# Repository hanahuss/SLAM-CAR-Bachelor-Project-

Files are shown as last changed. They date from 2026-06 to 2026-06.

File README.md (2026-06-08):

# SLAMborghini

> We built a SLAM car that explores rooms on its own, no laptop, no GPS, no internet. It sees the world through a spinning LiDAR, builds a live map as it drives, and figures out where to go next all by itself. Everything runs on two tiny ESP chips talking to each other in real time.

<p align="center">
  SLAMborghini RC Car
</p>

**Course:** [Making Intelligent Things (CS-358)](https://edu.epfl.ch/coursebook/en/making-intelligent-things-a-CS-358-A) EPFL Spring 2026

**Team:** Sara Amoussi · Chahd Achkrou · Hala Dina Ben Khaddah · Yassine Elhachimi · Hana Hesham Anwar Hussein

---

## Project Context

**Overview**

SLAMborghini implements **Simultaneous Localization and Mapping (SLAM)** on a resource-constrained RC car platform. The system solves the classic SLAM issue, building a map while simultaneously tracking position within it, built around three core components:

1. **Mapping**: The map is a sparse quadtree, it recursively divides the arena into smaller and smaller cells, only allocating memory for regions the robot has actually observed. This makes it extremely memory-efficient on the microcontroller. The car continuously builds its map using data from the RPLiDAR. Each ray traces through space, marking cells it passes through as free and stamping the wall it hits as occupied. Evidence builds up over time, the more a wall gets confirmed, the more confident the map becomes. When memory starts running low, the system automatically clears out uncertain areas while keeping the walls it's already sure about, so the map stays reliable without running out of space.
2. **Localization**: The car always knows where it is, even when things get tricky. Between each LiDAR scan, odometry keeps track of its position, the wheel encoder measures how far it's moved and the IMU sensor tracks which way it's turned. But small errors add up over time, so every time a new scan comes in, a two-level correlative scan matcher compares what the LiDAR sees with what's already on the map and corrects any drift. If the scan matcher doesn't find a confident match, the system falls back to pure odometry rather than applying a bad correction, keeping the map stable even in featureless environments.
3. **Navigation**: The car decides where to go by looking at frontiers, the boundaries between areas it has already mapped and areas still unknown. A Wavefront Frontier Detection algorithm scans outward through free cells, clusters these boundaries together, and picks the closest significant one as the next target. Hybrid A* then plans a path to that target, respecting the car's Ackermann steering constraints so the path is actually drivable. The path is streamed in chunks over UART from the ESP32-S3 to the Wemos, where a Pure Pursuit controller executes it in real time by continuously steering toward a lookahead point on the path.

<p align="center">
  <b>🗺️ Live SLAM Mapping Demo</b>
</p>
<p align="center">
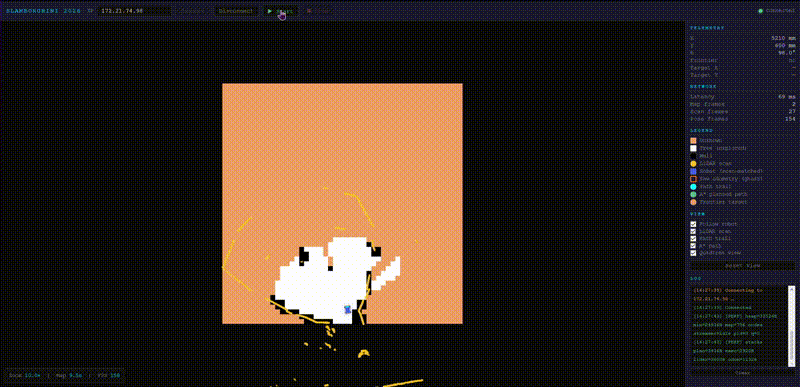
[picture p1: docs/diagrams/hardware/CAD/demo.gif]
SLAMborghini Demo
  
</p>

The key design decision is a **two-chip architecture**: the ESP32-S3 is the brain, it sees through the LiDAR, builds the map, figures out where to go, and sends path commands down to the Wemos over UART. The Wemos is the body, it owns the motors, the servo, and the sensors that measure motion, and it executes whatever the S3 tells it to drive. This clean split keeps the high-level thinking and the physical actuation fully independent, eliminating the timing conflicts that caused map drift when both were crammed onto one core.

Every bit of sensing, mapping, planning, and motor control happens on those two chips: no laptop, no cloud, no ROS. Just two microcontrollers talking to each other and figuring it out.

---

## Quick Jump To Detailed Documentation

For in-depth technical details, refer to the dedicated subsystem documentation:

<table>
<tr>
<td width="50%" align="center">

### 🧠 **[ESP32-S3: SLAM Brain](esp32s3/)**

LiDAR driver, quadtree map, correlative scan matching, RBPF, frontier detection, Hybrid A\*, Wi-Fi dashboard

</td>
<td width="50%" align="center">

### 🚗 **[Wemos D1 R32: Control Brain](wemos/)**

AS5600 encoder, ICM-20948 IMU, Ackermann odometry, Pure Pursuit controller, motor/servo control

</td>
</tr>
</table>

---

## Table of Contents

1. [Project Overview](#project-overview)
2. [Quick Start](#quick-start)
3. [Hardware](#hardware)
4. [System Architecture](#system-architecture)
5. [Software Setup](#software-setup)
6. [Configuration & Tuning](#configuration--tuning)
7. [Tools & Dashboard](#tools--dashboard)
8. [Known Issues & Limitations](#known-issues--limitations)
9. [Credits](#credits)

---

## Project Overview

### Vision

SLAMborghini is a fully autonomous RC car that you place in any unknown indoor space. It explores, builds a precise 2D floor plan in real time, and then navigates that space continuously, with no GPS signal, no connected laptop, and no cloud backend.

The full vision is laid out in the [Project Proposal](SLAMborghini-Proposal-1.pdf),  what's running today is Phase 1: full SLAM and autonomous patrol.

### How the Robot "Thinks"

The system runs a closed-loop pipeline, sense, plan, act, continuously and in real time, with responsibilities divided across two processors:

**High-Level Decision Making (ESP32-S3 SLAM Brain):**
1. **Perceive**: Read one 360° LiDAR scan (~100 ms per rotation)
2. **Correct**: Run correlative scan matching against the existing map to remove odometry drift
3. **Map**: Integrate the corrected scan into the sparse quadtree occupancy map
4. **Plan**: Detect exploration frontiers (free/unknown boundaries) → select nearest large frontier → run Hybrid A\* to compute a kinematically feasible path
5. **Command**:  Send the planned path to the Wemos over UART in small chunks of waypoints at a time, rather than all at once, so the Wemos always has the next steps ready without needing to buffer the entire route

**Low-Level Execution (Wemos D1 R32 Control Brain):**
1. **Localize**: Fuse AS5600 encoder distance with ICM-20948 gyro IMU heading at 100 Hz
2. **Track**: Follow the incoming path using Pure Pursuit; report consumed waypoints back
3. **Report**: Send odometry packets to the S3 at 20 Hz for pose integration

**Why this split?** SLAM and motor control have fundamentally different timing requirements. The S3 needs long uninterrupted windows to process LiDAR scans and update the map. The Wemos needs to fire motor commands at a tight, consistent rate to keep the car stable. When both tasks competed for the same processor, the motor interrupts would disturb the scan timing just enough to corrupt the map. Separating them onto dedicated chips eliminated that interference entirely.

### Technical Vocabulary

- **ESP32-S3**: Xtensa LX7 dual-core @ 240 MHz, 8 MB PSRAM, built-in Wi-Fi (SLAM Brain)
- **Wemos D1 R32**: ESP32 LX6 dual-core @ 240 MHz (Control Brain)
- **RPLiDAR C1**: 360° laser rangefinder, 12 m range, 10 Hz 
- **AS5600**: 12-bit I2C magnetic rotary encoder for wheel odometry
- **ICM-20948**: 9-DOF IMU; gyro Z only used (magnetometer disabled near motors)
- **IBT-4**: 50A MOSFET H-bridge motor driver
- **Quadtree**: Hierarchical spatial index; 4000 nodes × 12 B = 48 KB for a 10 m × 10 m map
- **Correlative scan matching**: Exhaustive 2-level grid search over (dx, dy, dθ), deterministic, ~5 ms
- **Hybrid A\***: Kinematically-constrained A\* that respects Ackermann steering limits
- **Pure Pursuit**: Geometric path-tracking controller for car-like robots
- **RBPF**: Rao-Blackwellized Particle Filter (module exists; currently pose integration uses direct complementary fusion)
- **UART bridge**: 115 200 baud serial link between S3 and Wemos; custom framed binary protocol

### Key Objectives 

- Real-time SLAM on a microcontroller with a full cycle time under 10 ms
- Sparse quadtree occupancy map of any unknown indoor room within 2 minutes of autonomous exploration
- Continuous autonomous frontier-based exploration and patrol along a Hybrid A\* route
- Stable differential odometry using the AS5600 magnetic encoder + ICM-20948 gyro fusion
- Live occupancy map streamed to a Wi-Fi dashboard accessible from any browser

---

## Quick Start

### Prerequisites Checklist

**Hardware:**
- Assembled SLAMborghini car (see [Hardware section](#hardware))
- 7.4 V LiPo battery (charged)
- USB-C to USB-C cable for flashing the ESP32-S3
- USB-C to Micro-USB cable for flashing the Wemos D1 R32
- Computer on the same Wi-Fi network as the car

**Software:**
- [PlatformIO Core](https://docs.platformio.org/en/latest/core/index.html) or VS Code extension

### Flash & Run

**Step 1: Clone the Repository**
```bash
git clone https://github.com/epfl-cs358/2026sp-SLAMborghini.git
cd 2026sp-SLAMborghini
```

**Step 2: Set Wi-Fi Credentials**

Edit [esp32s3/main.c](esp32s3/main.c) lines 74–75 before flashing:
```c
#define WIFI_SSID      
#define WIFI_PASSWORD  
```

**Step 3: Flash the ESP32-S3 (SLAM Brain)**
```bash
# In VS Code with PlatformIO:
# 1. Connect ESP32-S3 via USB
# 2. Open PlatformIO extension (alien icon)
# 3. Go on the terminal, type: cd esp32s3, and then type: pio run -e esp32s3 -t upload 
```

**Step 4: Flash the Wemos D1 R32 (Control Brain)**
```bash
# 1. Connect Wemos via USB
# 2. Click wemos → General → Upload, cd wemos, and then type: pio run -e wemos_slam -t upload 
```

**Step 5: Power Up**
1. Connect the 7.4 V LiPo battery
2. Open a browser and navigate to the IP address printed on the ESP32-S3 serial monitor
3. Open `tools/dashboard/live_dashboard.html`, enter the ESP32-S3 IP address
4. Click **Start** to begin autonomous exploration

**What to expect:**
- Live dashboard shows the occupancy map building in real time
- Robot explores frontiers and navigates toward them autonomously

---

## Hardware

### Component List

| # | Component | Model / Spec | Qty | Status |
|---|---|---|-----|---|
| 1 | ESP32-S3 dev board | ESP32-S3-WROOM-1, 8 MB PSRAM | 1 | Order |
| 2 | Magnetic encoder + magnet | AS5600 + 6 mm magnet | 1 | Order |
| 3 | RPLiDAR C1 | Slamtec, 12 m, 10 Hz | 1 | Existing |
| 4 | ICM-20948 IMU | 9-DOF, magnetometer disabled | 1 | Existing |
| 5 | Wemos D1 R32 | ESP32 LX6, 4 MB flash | 1 | Existing |
| 6 | ESP32-CAM AIThinker | OV2640 2 MP | 1 | Existing (stub only) |
| 7 | IBT-4 motor driver | 50A MOSFET H-bridge | 1 | Existing |
| 8 | DMS15-270 servo | 15 kg·cm, 270° range | 1 | Existing |
| 9 | LM2596 buck converter | 7.4 V → 5 V, 3 A | 1 | Existing |
| 10 | LiPo battery 7.4 V 3000 mAh 2S | RedPower + HW-391 BMS | 1 | Existing |
| 11 | Active buzzer 5 V | 85 dB piezo | 1 | Stock |
| 12 | Electrolytic cap 1000 µF 16V | Motor/logic rail decoupling | 2 | Stock |
| 13 | 1N4007 diode | Flyback protection | 4 | Stock |
| 14 | 4.7 kΩ resistor | I2C pull-ups (6 total) | 6 | Stock |

### 3D Printed Parts

All custom mechanical parts were designed in CAD and printed in PLA. Source files (`.step` for editing, `.stl` for slicing) are in [`docs/diagrams/hardware/CAD/`](docs/diagrams/hardware/CAD/).

<table>
<tr>
<td width="50%" align="center">

**Encoder Bracket**

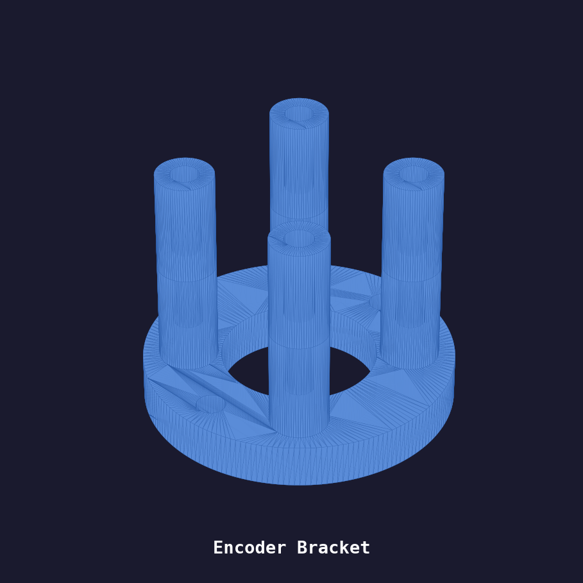
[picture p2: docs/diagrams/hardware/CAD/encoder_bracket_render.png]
Encoder Bracket


Mounts the AS5600 encoder at the rear wheel<br>
[📄 STL](docs/diagrams/hardware/CAD/Encoder_Bracket.stl) · [📐 STEP](docs/diagrams/hardware/CAD/Encoder_Bracket_v1.step)

</td>
<td width="50%" align="center">

**Magnet Support**

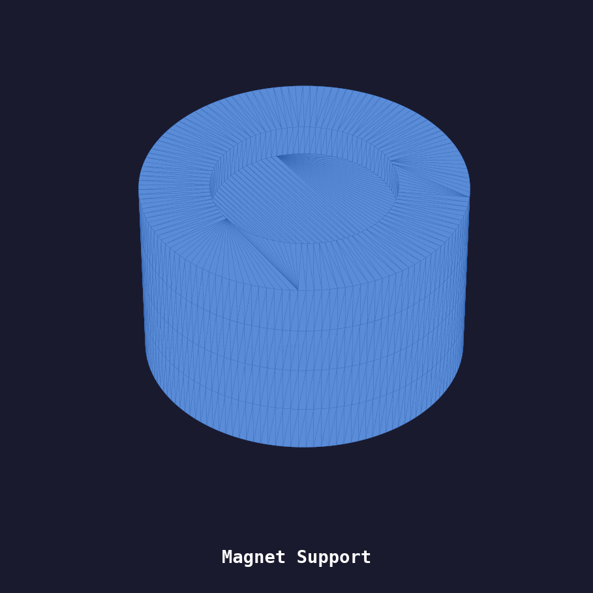
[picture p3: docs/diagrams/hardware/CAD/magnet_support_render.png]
Magnet Support


Holds the 6 mm magnet centred on the wheel axle<br>
[📄 STL](docs/diagrams/hardware/CAD/Magnet_Support.stl)

</td>
</tr>
<tr>
<td width="50%" align="center">

**Protection Cover**

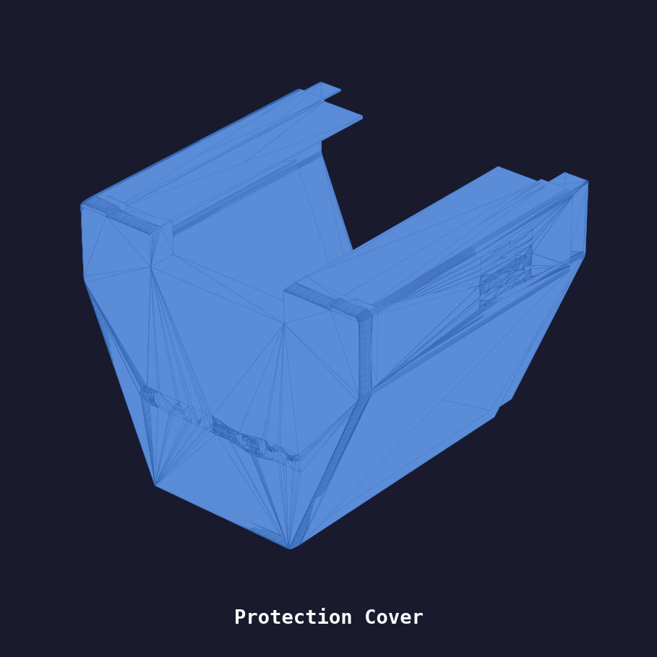
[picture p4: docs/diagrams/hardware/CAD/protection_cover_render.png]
Protection Cover


Shield over the electronics bay<br>
[📄 STL](docs/diagrams/hardware/CAD/Protection_Cover.stl) · [📐 STEP](docs/diagrams/hardware/CAD/Protection_Cover.step)

</td>
<td width="50%" align="center">

**Electronics Tray**

Electronics Tray

Chassis-mounted tray for all PCBs and modules<br>
[📄 STL](docs/diagrams/hardware/CAD/electronics_tray.stl) · [📐 STEP](docs/diagrams/hardware/CAD/electronics_tray.step)

</td>
</tr>
</table>

> **Recommended print settings:** PLA, 0.2 mm layer height, 20% infill, 3 perimeters. The Encoder Bracket and Magnet Support are precision-fit parts, print at 100% scale with no scaling.

### Pin Assignment Summary

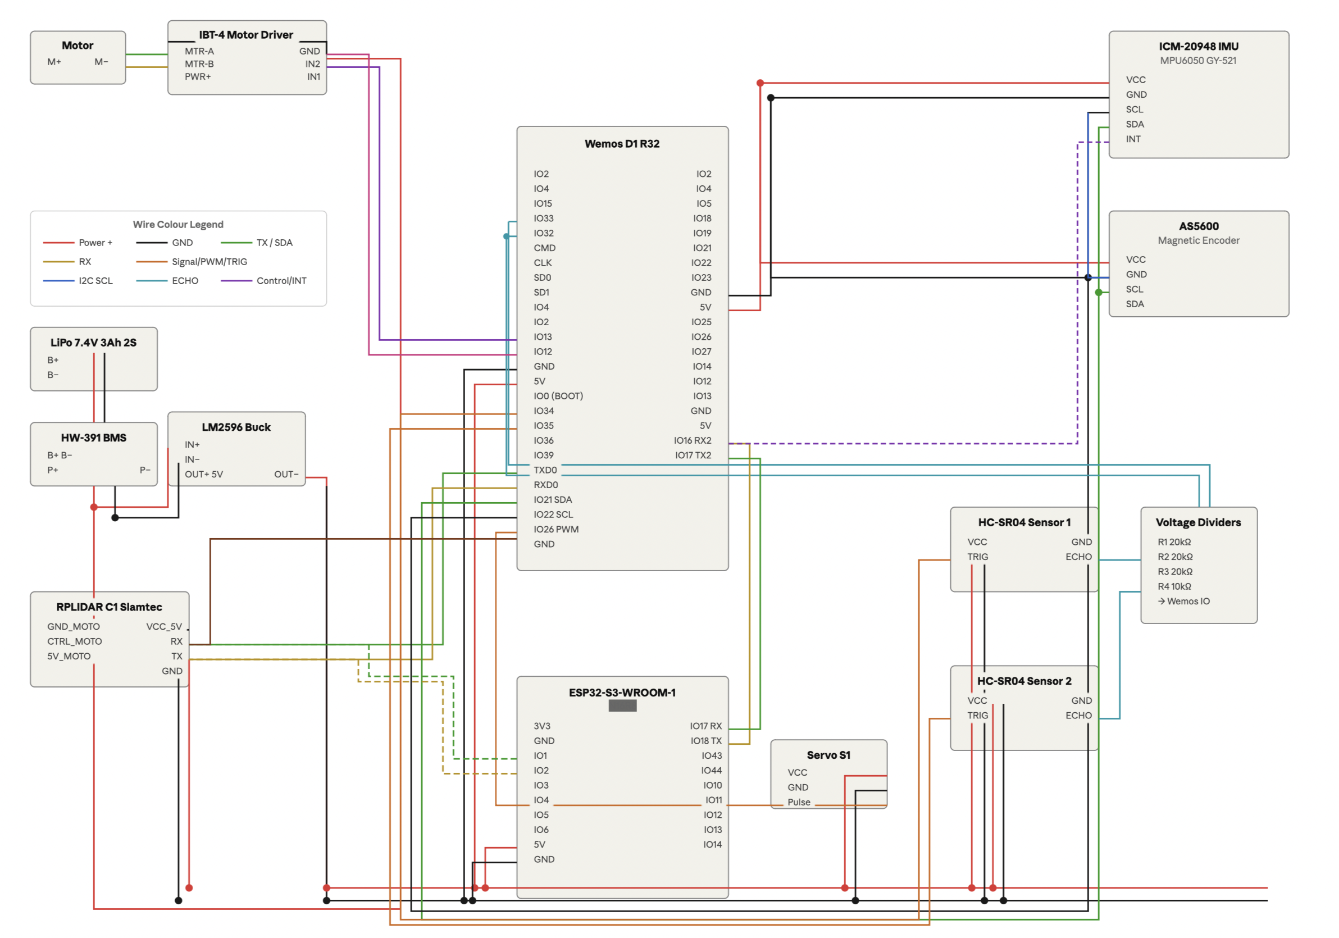
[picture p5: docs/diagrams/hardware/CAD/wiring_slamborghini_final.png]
Wiring Diagram


**ESP32-S3:**

| GPIO | Function | Connected to |
|---|---|---|
| GPIO14 (RX) | UART1 LiDAR | RPLiDAR C1 TX |
| GPIO13 (TX) | UART1 LiDAR | RPLiDAR C1 RX |
| GPIO17 (TX) | UART2 Bridge → Wemos | Wemos GPIO16 |
| GPIO16 (RX) | UART2 Bridge ← Wemos | Wemos GPIO17 |

**Wemos D1 R32:**

| GPIO | Function | Connected to |
|---|---|---|
| GPIO21 | I2C SDA | AS5600 + ICM-20948 |
| GPIO22 | I2C SCL | AS5600 + ICM-20948 |
| GPIO16 (RX) | UART2 Bridge | ESP32-S3 GPIO17 |
| GPIO17 (TX) | UART2 Bridge | ESP32-S3 GPIO16 |
| GPIO19 | IBT-4 RPWM (forward) | IBT-4 IN1 |
| GPIO13 | IBT-4 LPWM (backward) | IBT-4 IN2 |
| GPIO2 | Servo PWM | DMS15-270 |
| GPIO14/27 | HC-SR04 A TRIG/ECHO | Front-left sonar |
| GPIO25/26 | HC-SR04 B TRIG/ECHO | Front-right sonar |

### Power Architecture

The system runs from a single 7.4 V LiPo with a dual-rail split:

| Rail | Voltage | Source | Powers |
|---|---|---|---|
| Motor rail | 7.4 V direct | LiPo → HW-391 BMS → IBT-4 | IBT-4 only |
| Logic rail | 5 V regulated | LiPo → HW-391 BMS → LM2596 | All ESP32 boards, RPLiDAR, HC-SR04, servo |
| 3.3 V sub-rail | 3.3 V | Onboard ESP32 regulators | ICM-20948, AS5600 |

Motor GND and logic GND are separated physically; one controlled common reference point near power entry.

---

## System Architecture

Computation is split across two ESP32s with clearly defined roles:

- **ESP32-S3**: SLAM pipeline, frontier exploration, global planning, Wi-Fi dashboard
- **Wemos D1 R32**: Sensor fusion, Pure Pursuit execution, motor/servo control

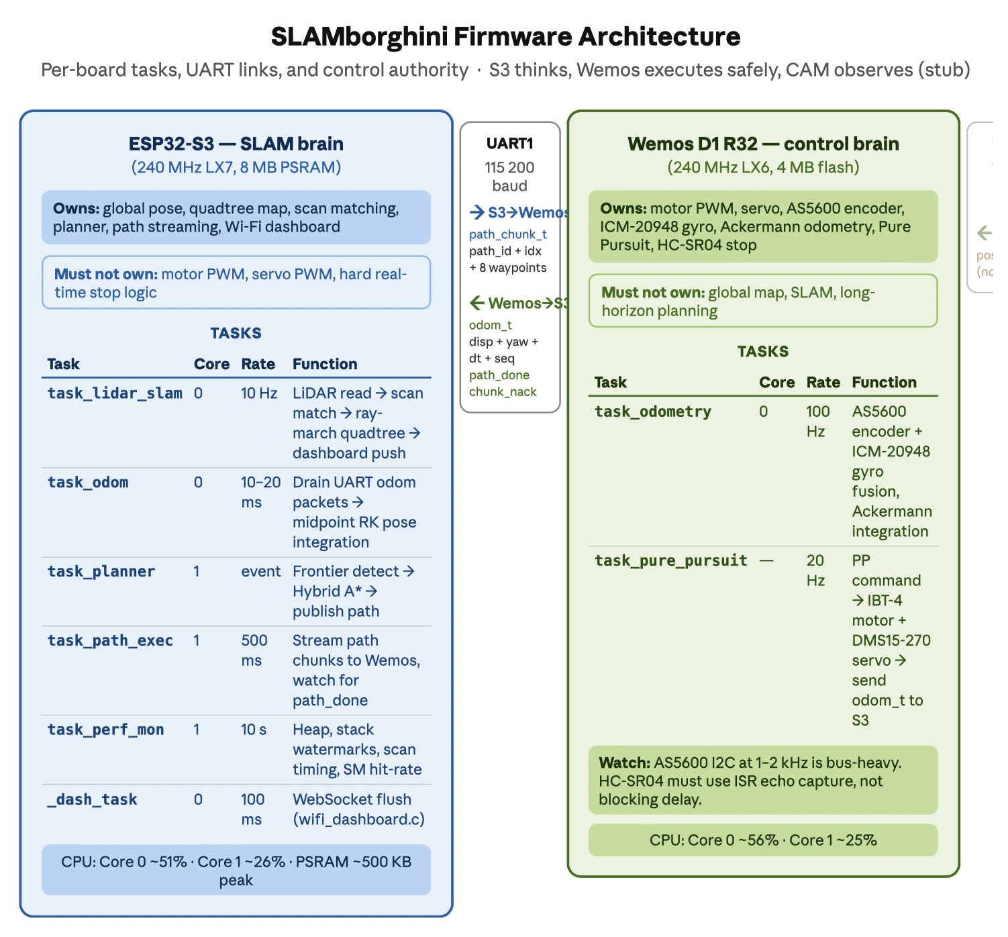
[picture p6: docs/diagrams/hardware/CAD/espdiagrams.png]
Firmware Architecture


Both run **FreeRTOS** for priority-based real-time scheduling. The S3 connects to the existing Wi-Fi network and serves a live HTTP + WebSocket dashboard.

```
────────────────────────────────────────────────────────────────────────
  ESP32-S3  SLAM Brain  (10 Hz SLAM loop)
  • LiDAR driver + correlative scan matching
  • Sparse quadtree occupancy map (48 KB, 4000 nodes, 10 m × 10 m)
  • RBPF 20-particle pose estimator
  • Wavefront Frontier Detection + Hybrid A* planner
  • Frontier blacklisting, path streaming to Wemos
  • Wi-Fi HTTP + WebSocket dashboard (live map, pose, path overlay)
────────────────────────────────────────────────────────────────────────
                     UART  115 200 baud
  odom_t packets ←   (linear_disp_mm, yaw_rate_imu, dt_ms, seq)
  path_chunk_t  →    (path_id, start_index, 8 waypoints per chunk)
  path_done     ←    (signal: path complete, please replan)
  chunk_nack    ←    (signal: out-of-order chunk, resend from index N)
────────────────────────────────────────────────────────────────────────
  Wemos D1 R32  Control Brain  (20–100 Hz control loops)
  • AS5600 encoder + ICM-20948 gyro fusion at 100 Hz
  • Ackermann odometry model
  • Pure Pursuit path tracking (20 Hz, 32-waypoint ring buffer)
  • IBT-4 motor PWM + DMS15-270 servo control

────────────────────────────────────────────────────────────────────────
```

### ESP32-S3 Tasks

| Task | Core | Priority | Period | Function |
|---|---|---|---|---|
| `task_lidar_slam` | 0 | 7 | ~100 ms | LiDAR read → scan match → ray-march → dashboard push |
| `task_odom` | 0 | 6 | 10 ms | Drain UART odom packets → midpoint RK pose integration |
| `task_planner` | 1 | 3 | event-driven | Frontier detect → Hybrid A\* → publish path to exec |
| `task_path_exec` | 1 | 3 | 500 ms | Stream path chunks to Wemos, watch for path_done |
| `task_perf_mon` | 1 | 1 | 10 s | Heap, stack watermarks, scan timing, SM hit-rate |
| `_dash_task` | 0 | 1 | 100 ms | WebSocket flush (inside wifi_dashboard.c) |

### Wemos D1 R32 Tasks

| Task | Core | Priority | Period | Function |
|---|---|---|---|---|
| `task_odometry` | — | 5 | 10 ms (100 Hz) | AS5600 read + IMU fusion + Ackermann integration |
| `task_pure_pursuit` | — | 4 | 50 ms (20 Hz) | PP command → motor/servo → send odom_t to S3 |

### SLAM Pipeline (one cycle)

```
LiDAR scan (~100 ms blocking read)
    │
    ▼
Snapshot raw odometry pose
    │
    ▼
Correlative scan matching (~5 ms)
  • Coarse: ±100 mm / 50 mm,  ±8° / 4°  → 125 candidates
  • Fine:   ±20 mm / 10 mm,   ±2° / 1°  → 125 candidates
  • Rejection: hit-rate < 10%  OR  |Δ| > 80 mm / 12°
    │
    ▼
Apply correction to running pose estimate
    │
    ▼
Ray-march scan into quadtree map (Bresenham per beam)
  • HIT +30, MISS −2  (15:1 ratio — walls resist free-space erosion)
  • Auto-compact at 85% pool usage: snapshot walls ≥ 10, wipe, re-insert
    │
    ▼
Frontier detection + A* (on planner task, 500 ms replan budget)
    │
    ▼
Stream path chunks to Wemos (8 waypoints/chunk, NACK-retry protocol)
```

### Communication Protocol (UART Bridge)

| Direction | Message | Size | Rate |
|---|---|---|---|
| Wemos → S3 | `odom_t` (linear_disp + yaw_rate + dt + seq + consumed_wp) | 20 B | 20 Hz |
| S3 → Wemos | `path_chunk_t` (path_id + start_index + 8 waypoints) | 136 B | on replan |
| Wemos → S3 | `path_done` marker | 4 B | on path complete |
| Wemos → S3 | `chunk_nack` (path_id + expected_index) | 4 B | on out-of-order |

The path streamer on the S3 maintains a sliding window of the planned path and proactively tops up the Wemos ring buffer as consumed waypoints are reported.

---

## Software Setup

### Project Structure

```
2026sp-SLAMborghini/
├── esp32s3/                   # SLAM Brain firmware
│   ├── main.c                 # Tasks: lidar_slam, odom, planner, path_exec, perf_mon
│   └── src/
│       ├── lidar_driver.c/h   # RPLiDAR C1 UART driver
│       ├── lidar_to_map.c/h   # Bresenham ray-march into quadtree
│       ├── quadtree_map.c/h   # Sparse quadtree occupancy map
│       ├── scan_matcher.c/h   # Two-level correlative scan matching
│       ├── rbpf.c/h           # Rao-Blackwellized Particle Filter
│       ├── frontier_detector.c/h  # Wavefront Frontier Detection (WFD)
│       ├── hybrid_astar.c/h   # Hybrid A* path planner
│       ├── path_streamer.c/h  # Chunked path streaming + NACK retry
│       ├── uart_bridge.c/h    # Framed binary UART protocol
│       └── wifi_dashboard.c/h # HTTP + WebSocket live dashboard
│
├── wemos/                     # Control Brain firmware
│   ├── main.c                 # Tasks: task_odometry, task_pure_pursuit
│   ├── imu_gyro.c/h           # ICM-20948 gyro-Z driver
│   └── src/
│       ├── task_odometry.c/h  # 100 Hz sensor fusion task
│       ├── imu_encoder_driver.c/h  # AS5600 encoder + IMU read
│       ├── encoder_ackermann_odometry.c/h  # Ackermann kinematic model
│       ├── pure_pursuit_controller.c/h  # Pure Pursuit + ring buffer
│       └── uart_bridge.c/h    # Framed binary UART protocol (Wemos side)
│
├── esp32cam/                  # Vision Brain (stub — not functional)
│   └── main.c                 # posture_classifier_init() only; loop commented out
│
├── tools/
│   ├── dashboard/
│   │   ├── live_dashboard.html       # Main browser UI (WebSocket map + pose)
│   │   ├── frontier_dashboard.html   # Frontier overlay debug view
│   │   └── playback_dashboard.html   # Replay from room.log
│   ├── parse_room/
│   │   └── parse_room.py             # Convert room.log to map image
│   └── slam_sim.py                   # SLAM simulator (desktop testing)
│
├── hardware_pins.h            # All GPIO assignments (edit here to rewire)
├── types.h                    # Shared data structures (both boards)
└── profiler/                  # FreeRTOS CPU profiling helper
```

### Development Environment

**Prerequisites:**
- [PlatformIO Core](https://docs.platformio.org/en/latest/core/index.html) or VS Code extension
- ESP-IDF v5.x (bundled by PlatformIO, no separate install needed)

### Flash ESP32-S3

```bash
cd esp32s3
# Via PlatformIO CLI:
pio run -e esp32s3 -t upload
pio device monitor
```

### Flash Wemos D1 R32

```bash
cd wemos
pio run -e wemos_slam -t upload 
pio device monitor
```

### Wi-Fi Configuration

Edit [esp32s3/main.c](esp32s3/main.c) before flashing:
```c
#define WIFI_SSID      "your_network"
#define WIFI_PASSWORD  "your_password"
```

The ESP32-S3 connects to your existing Wi-Fi (station mode, not AP). The IP address is printed on the serial monitor at boot.

---

## Configuration & Tuning

### Map Parameters

```c
// esp32s3/main.c — app_main()
quadtree_map_init(&s_map, 10000.0f, 10000.0f, 156.0f);
//                         ^width mm  ^height mm  ^leaf cell mm
```

10 m × 10 m arena with 156 mm leaf resolution (10 000 / 64, depth 7).

```c
// esp32s3/src/quadtree_map.h
#define QT_POOL_SIZE  4000   // 4000 × 12 B = 48 KB
#define QT_MAX_DEPTH  7
#define QT_HIT_INC    30     // log-odds increment on obstacle hit
#define QT_MISS_DEC  (-2)    // log-odds decrement per free-ray pass
```

**Trade-offs:**
- Larger `QT_POOL_SIZE` → more map detail → more RAM (must fit in D-cache for scan matching)
- Higher `QT_HIT_INC` / lower `QT_MISS_DEC` ratio → walls persist longer → less flicker, slower erasure

### Scan Matcher Parameters

```c
// esp32s3/src/scan_matcher.c
// Coarse: ±100 mm / 50 mm step,  ±8° / 4° step  → 125 candidates
// Fine:   ±20 mm  / 10 mm step,  ±2° / 1° step  → 125 centred on coarse best
// Rejection thresholds:
//   hit-rate < 10%            → map too sparse
//   improvement < 5 beams     → no real gain
//   |dx| or |dy| > 80 mm     → implausibly large jump
//   |dθ| > 12°                → implausibly large rotation
```

### Pure Pursuit Parameters

```c
// wemos/src/pure_pursuit_controller.c — pp_init()
pp->wheelbase_mm      = 260.0f;    // front-to-rear axle distance
pp->lookahead_mm      = 350.0f;    // look-ahead distance
pp->fixed_speed_mm_s  = 150.0f;    // constant forward speed
pp->goal_tolerance_mm = 120.0f;    // waypoint considered reached
```

**Tuning guide:**
- `lookahead_mm` too small → oscillation at corners
- `lookahead_mm` too large → cuts corners, overshoots frontiers
- `fixed_speed_mm_s` higher → faster exploration, worse scan quality (motion blur)

### Servo Calibration

```c
// wemos/main.c
#define SERVO_DUTY_CENTER  4700u    // measured true straight
#define SERVO_DUTY_LEFT    3500u    // ~65° left
#define SERVO_DUTY_RIGHT   5900u    // ~65° right
#define SERVO_STEER_GAIN   1042.0f  // LEDC counts per radian
```

### FreeRTOS Task Priorities

```c
// ESP32-S3
task_lidar_slam : Core 0, Priority 7, Stack 6 KB
task_odom       : Core 0, Priority 6, Stack 3 KB
task_planner    : Core 1, Priority 3, Stack 6 KB
task_path_exec  : Core 1, Priority 3, Stack 5 KB
task_perf_mon   : Core 1, Priority 1, Stack 3 KB
_dash_task      : Core 0, Priority 1, Stack 4 KB  (inside wifi_dashboard.c)

// Wemos D1 R32
task_odometry     : Priority 5, Stack 4 KB
task_pure_pursuit : Priority 4, Stack 4 KB
```

---

## Tools & Dashboard

### Live Dashboard

Open [tools/dashboard/live_dashboard.html](tools/dashboard/live_dashboard.html) in any browser. Enter the ESP32-S3 IP address and connect.

**Dashboard features:**
- Real-time occupancy map (quadtree cells rendered as coloured pixels)
- Robot pose marker (blue car icon) and raw odometry ghost (orange, pre-scan-match)
- Planned A\* path overlay (waypoint polyline)
- Active frontier target marker
- Live LiDAR scan overlay (polar fan)
- Log panel showing `[PLAN]`, `[SM]`, `[PERF]` messages
- **Start / Stop** buttons to gate autonomous exploration

---

## Known Issues & Limitations

| Issue | Status | Notes |
|---|---|---|
| Static environment assumed | Active | Dynamic obstacles (people) are not filtered from the map |
| ESP32-CAM not functional | Not started | Camera init runs; posture classifier loop is commented out |
| Human detection / Phase 2 | Not started | S3KM1110 mmWave not wired; no alert pipeline |
| No loop closure | Not started | Map fingerprinting module described in proposal; not implemented |

---

## Credits

### Project Team

SLAMborghini was developed as part of the [Making Intelligent Things (CS-358)](https://edu.epfl.ch/coursebook/en/making-intelligent-things-a-CS-358-A) course at **EPFL** (École Polytechnique Fédérale de Lausanne), Spring 2026.

**Team:** Sara Amoussi · Chahd Achkrou · Hala Dina Ben Khaddah · Yassine Elhachimi · Hana Hesham Anwar Hussein

### Key Technologies & References

- **FreeRTOS** — Real-time operating system for multitasking on ESP32
- **ESP-IDF** — Espressif IoT Development Framework
- **RPLiDAR C1 SDK** — Slamtec LiDAR interface
- **PlatformIO** — Development platform and build system for ESP32
- Correlative scan matching: [Olson 2009, "Real-time correlative scan matching"](https://april.eecs.umich.edu/papers/details.xml?name=olson2009icra)
- Hybrid A\*: [Dolgov et al., "Practical Search Techniques in Path Planning for Autonomous Driving"](https://ai.stanford.edu/~ddolgov/papers/dolgov_gpp_stair08.pdf)
- Pure Pursuit: [Coulter 1992, "Implementation of the Pure Pursuit Path Tracking Algorithm"](https://www.ri.cmu.edu/pub_files/pub3/coulter_r_craig_1992_1/coulter_r_craig_1992_1.pdf)

### Use of AI Tools in Development

This project was developed with assistance from AI-powered development tools in accordance with EPFL academic integrity guidelines.

**AI did NOT:** define project goals, make architectural decisions, perform hardware assembly or wiring, collect experimental data, or validate performance on the physical car.

---

**Questions or issues?** Open a GitHub issue on the [project repository](https://github.com/epfl-cs358/2026sp-SLAMborghini). For any further questions or feedback, contact: hana.hussein@epfl.ch chahd.achkrou@epfl.ch sara.amoussi@epfl.ch hala.benkhaddah@epfl.ch yassine.elhachimi@epfl.ch

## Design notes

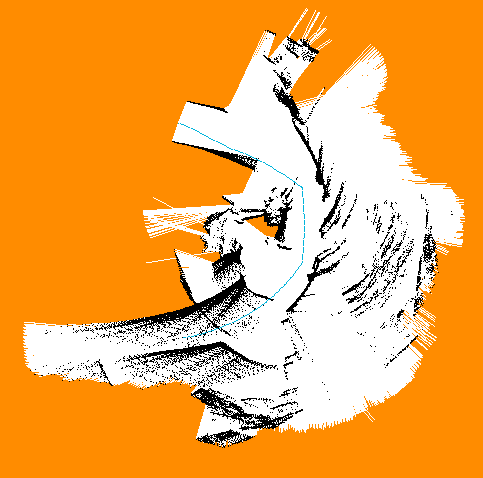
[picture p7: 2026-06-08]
tools/dashboard/lidar_map.png

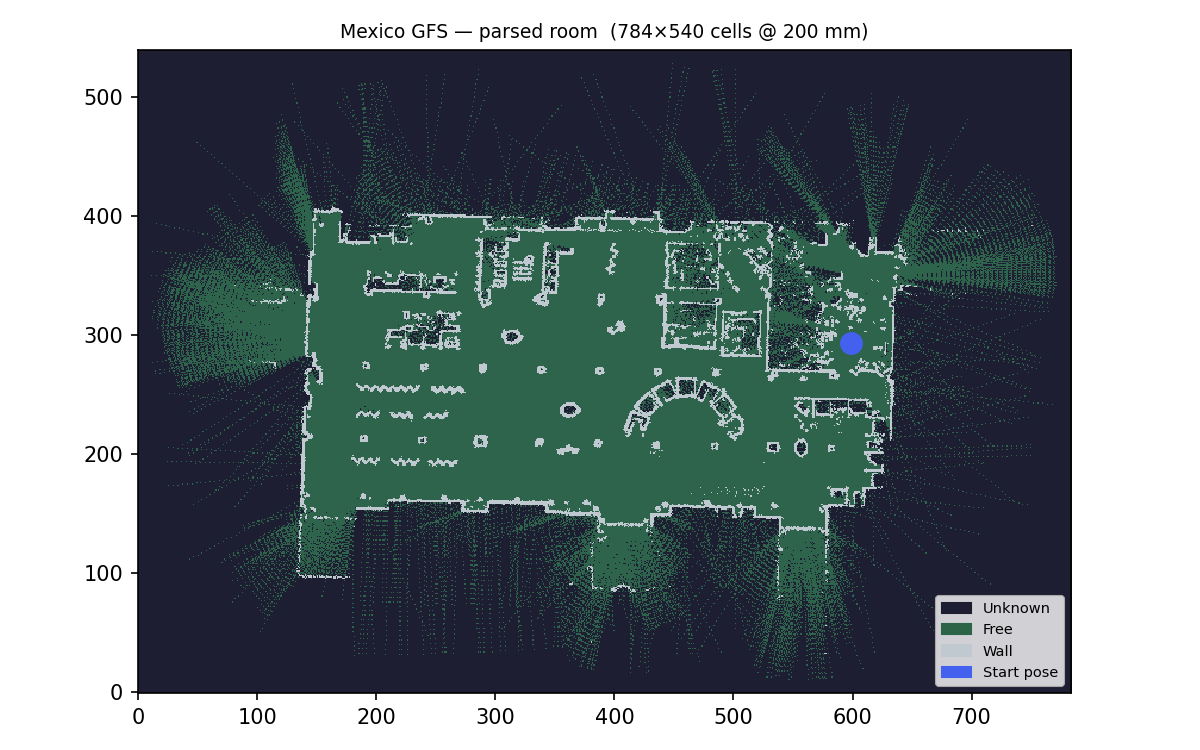
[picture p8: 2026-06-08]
tools/parse_room/room_preview.png

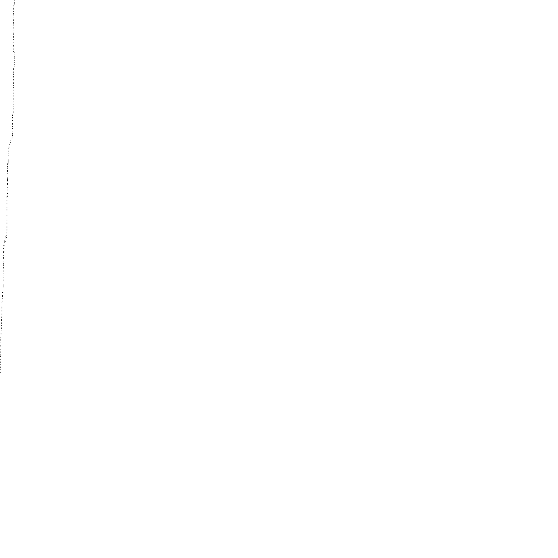
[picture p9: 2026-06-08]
tools/dashboard/room_map.png

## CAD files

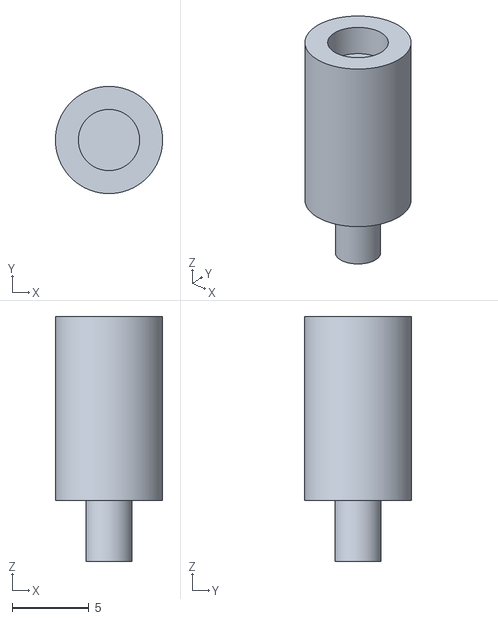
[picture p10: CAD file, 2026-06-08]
docs/diagrams/hardware/CAD/Magnet_Support.stl
7.00 x 7.00 x 16.0

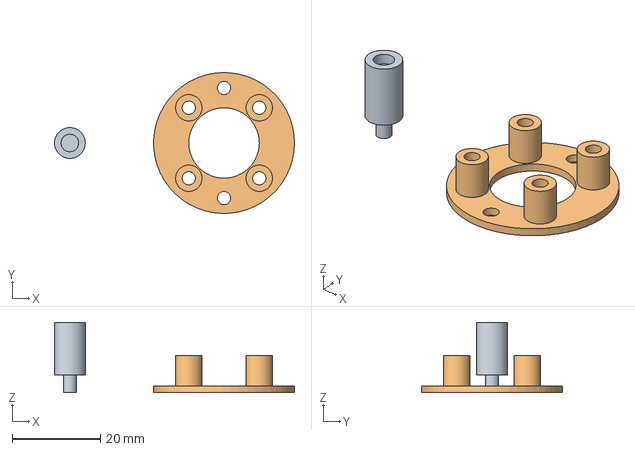
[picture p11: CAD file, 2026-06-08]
docs/diagrams/hardware/CAD/Encoder_Bracket_v1.step
54.5 x 32.0 x 16.0 mm

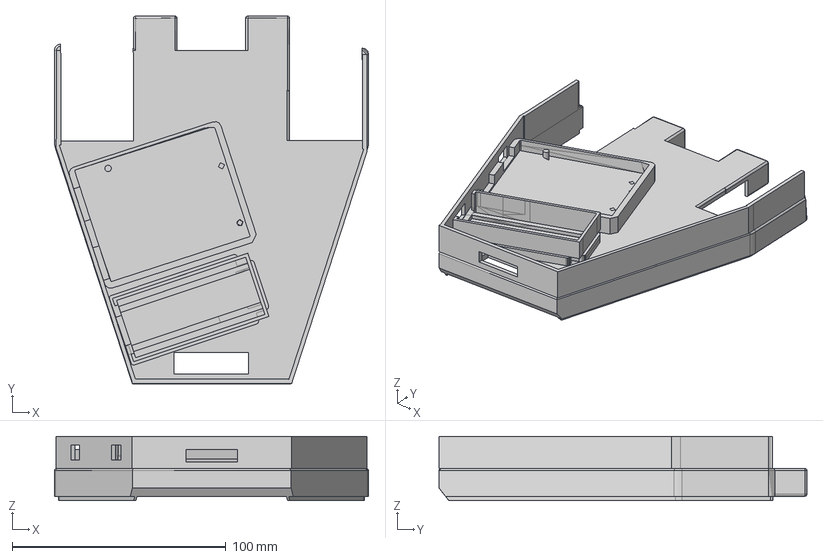
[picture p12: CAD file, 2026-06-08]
docs/diagrams/hardware/CAD/electronics_tray.step
147.0 x 172.1 x 30.0 mm

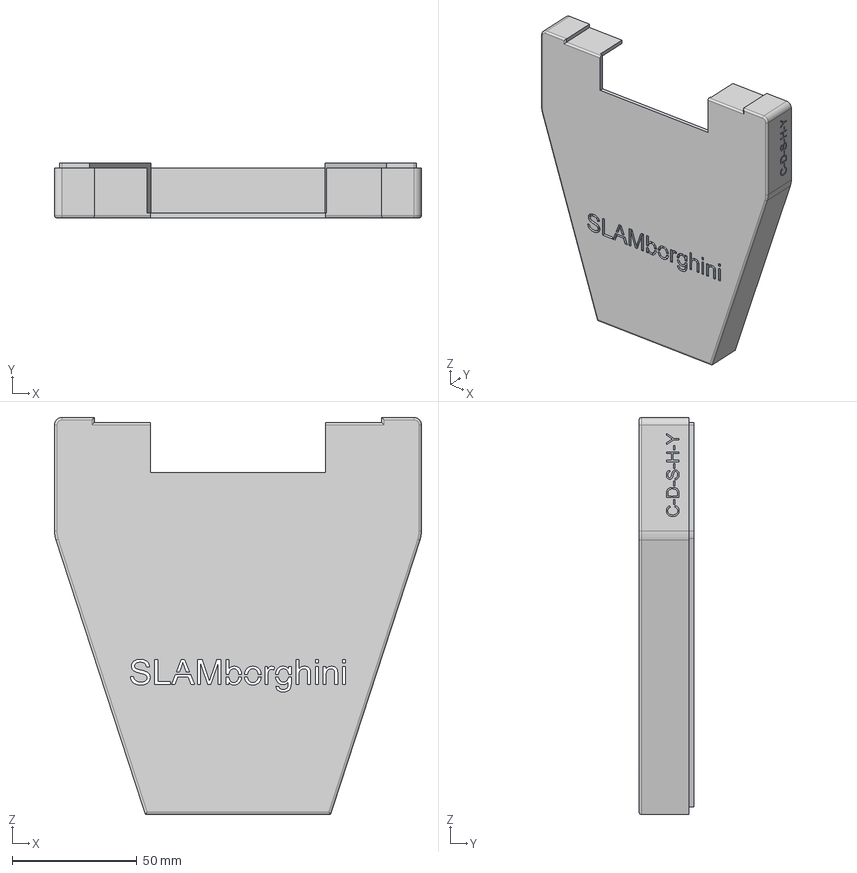
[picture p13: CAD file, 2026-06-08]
docs/diagrams/hardware/CAD/Protection_Cover.step
147.0 x 22.0 x 159.0 mm

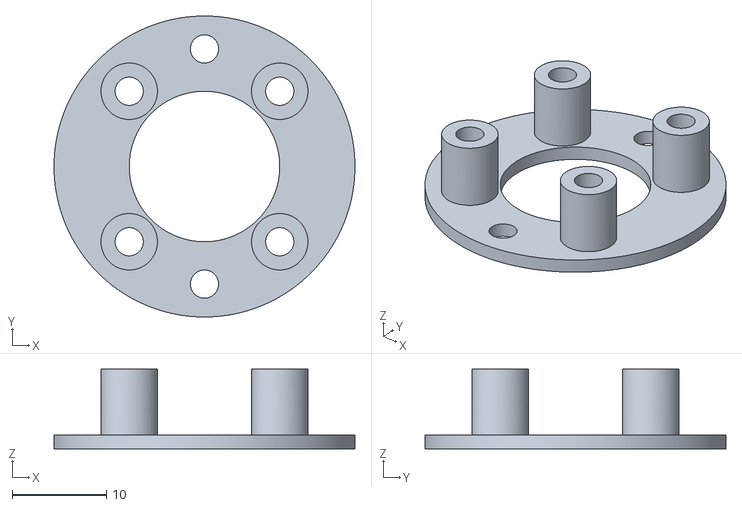
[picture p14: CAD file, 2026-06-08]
docs/diagrams/hardware/CAD/Encoder_Bracket.stl
32.0 x 32.0 x 8.50

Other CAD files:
docs/diagrams/hardware/CAD/Protection_Cover.stl
docs/diagrams/hardware/CAD/electronics_tray.stl

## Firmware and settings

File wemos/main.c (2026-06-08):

/**
 * wemos/main.c
 *
 * Wemos D1 R32 — motion controller + odometry sender.
 *
 * Two-board architecture:
 *   ESP32-S3 (SLAM brain) ──UART──► Wemos D1 R32 (motion controller)
 *
 * Two-task architecture:
 *   task_odometry     priority 5, 100 Hz  — AS5600 + ICM-20948 fusion,
 *                                           publishes odom_pose_t
 *   task_pure_pursuit priority 4,  20 Hz  — receives path_chunk_t from
 *                                           ESP32-S3, runs PP controller,
 *                                           drives servo + motor, sends
 *                                           odom_t back to ESP32-S3
 *
 * Coordinate-frame note:
 *   The ESP32-S3 generates paths in its own world frame (origin at map
 *   bottom-centre, 5000 mm, 500 mm, heading π/2).  The Wemos odometry
 *   starts at (0, 0, 0).  On path receipt, waypoints are rigidly
 *   transformed so that wp[0] aligns with the current Wemos pose.
 */

#include "hardware_pins.h"
#include "imu_gyro.h"
#include "src/uart_bridge.h"
#include "src/pure_pursuit_controller.h"
#include "src/task_odometry.h"
#include "src/imu_encoder_driver.h"
#include "src/encoder_ackermann_odometry.h"

#include "driver/ledc.h"
#include "driver/uart.h"
#include "freertos/FreeRTOS.h"
#include "freertos/task.h"
#include "esp_log.h"
#include "esp_timer.h"

#include <math.h>
#include <string.h>

static const char *TAG = "wemos_main";

/* ── Motor ────────────────────────────────────────────────────────────────── */
#define MOTOR_PWM_FREQ_HZ   25000     /* above hearing range — eliminates audible tone */
#define MOTOR_PWM_RES       LEDC_TIMER_8_BIT
#define MOTOR_DUTY_FWD      28        /* slow enough for PP to track corners cleanly */
#define CH_FWD              LEDC_CHANNEL_3
#define CH_BWD              LEDC_CHANNEL_2

/* ── Servo — calibrated values ────────────────────────────────────────────── */
#define SERVO_PWM_FREQ_HZ   50
#define SERVO_PWM_RES       LEDC_TIMER_16_BIT
#define SERVO_CH            LEDC_CHANNEL_0
#define SERVO_DUTY_CENTER   4700u     /* measured true straight */
#define SERVO_STEER_GAIN    1042.0f   /* LEDC counts per radian */
#define SERVO_MAX_STEER_RAD 1.134f    /* 65° — physical steering limit */
/* Derived from center ± (max_steer_rad × gain): 4700 ± (1.134 × 1042) ≈ 4700 ± 1182 */
#define SERVO_DUTY_LEFT     (SERVO_DUTY_CENTER - (uint32_t)(SERVO_MAX_STEER_RAD * SERVO_STEER_GAIN))
#define SERVO_DUTY_RIGHT    (SERVO_DUTY_CENTER + (uint32_t)(SERVO_MAX_STEER_RAD * SERVO_STEER_GAIN))

/* ── PP loop rate ─────────────────────────────────────────────────────────── */
#define PP_PERIOD_MS    50u   /* 20 Hz */

/* ════════════════════════════════════════════════════════════════════════════
 * Actuator helpers
 * ════════════════════════════════════════════════════════════════════════════ */

static void motor_set(float speed_mm_s)
{
    if (speed_mm_s > 0.0f) {
        ledc_set_duty(LEDC_LOW_SPEED_MODE, CH_FWD, (uint32_t)MOTOR_DUTY_FWD);
        ledc_set_duty(LEDC_LOW_SPEED_MODE, CH_BWD, 0u);
    } else if (speed_mm_s < -10.0f) {
        /* Reverse: drive CH_BWD; CH_FWD must be zero to avoid H-bridge shoot-through. */
        ledc_set_duty(LEDC_LOW_SPEED_MODE, CH_FWD, 0u);
        ledc_set_duty(LEDC_LOW_SPEED_MODE, CH_BWD, (uint32_t)MOTOR_DUTY_FWD);
    } else {
        ledc_set_duty(LEDC_LOW_SPEED_MODE, CH_FWD, 0u);
        ledc_set_duty(LEDC_LOW_SPEED_MODE, CH_BWD, 0u);
    }
    ledc_update_duty(LEDC_LOW_SPEED_MODE, CH_FWD);
    ledc_update_duty(LEDC_LOW_SPEED_MODE, CH_BWD);
}

static void servo_set_deg(float steering_deg)
{
    float rad = (steering_deg - 90.0f) * ((float)M_PI / 180.0f);
    int32_t duty = (int32_t)SERVO_DUTY_CENTER + (int32_t)(rad * SERVO_STEER_GAIN);
    if (duty < (int32_t)SERVO_DUTY_LEFT)  duty = (int32_t)SERVO_DUTY_LEFT;
    if (duty > (int32_t)SERVO_DUTY_RIGHT) duty = (int32_t)SERVO_DUTY_RIGHT;
    ledc_set_duty(LEDC_LOW_SPEED_MODE, SERVO_CH, (uint32_t)duty);
    ledc_update_duty(LEDC_LOW_SPEED_MODE, SERVO_CH);
}

static float wrap_rad(float a)
{
    a = fmodf(a, 2.0f * (float)M_PI);
    if (a >  (float)M_PI) a -= 2.0f * (float)M_PI;
    if (a < -(float)M_PI) a += 2.0f * (float)M_PI;
    return a;
}

/* ════════════════════════════════════════════════════════════════════════════
 * task_pure_pursuit  —  priority 4, 20 Hz
 * ════════════════════════════════════════════════════════════════════════════ */

/* SE(2) transform state: aligns S3-world waypoints to Wemos local frame.
 * Computed once per path_id from the first chunk (start_index == 0).
 * Stored here (not inside the PP struct) so it survives between chunks. */
static uint16_t s_tf_path_id = 0xFFFFu;  /* UINT16_MAX = no valid transform */
static float    s_tf_c, s_tf_sv;          /* cos(dth), sin(dth) */
static float    s_tf_dth = 0.0f;          /* heading offset: Wemos_theta - S3_theta */
static float    s_tf_base_x, s_tf_base_y, s_tf_base_th;
static float    s_tf_wx, s_tf_wy, s_tf_wth;

static void apply_transform_to_chunk(path_chunk_t *chunk)
{
    for (uint8_t i = 0; i < chunk->count; i++) {
        float rx = chunk->wp[i].x - s_tf_base_x;
        float ry = chunk->wp[i].y - s_tf_base_y;
        chunk->wp[i].x     = s_tf_wx + (s_tf_c * rx - s_tf_sv * ry);
        chunk->wp[i].y     = s_tf_wy + (s_tf_sv * rx + s_tf_c  * ry);
        chunk->wp[i].theta = wrap_rad(chunk->wp[i].theta - s_tf_base_th + s_tf_wth);
    }
}

static void task_pure_pursuit(void *pvParameters)
{
    (void)pvParameters;

    pure_pursuit_controller_t pp;
    pp_init(&pp);

    float    prev_dist_m     = imu_encoder_driver_get_distance_m();
    float    prev_heading    = imu_encoder_driver_get_yaw_rad();
    int64_t  prev_us         = esp_timer_get_time();
    uint32_t odom_seq        = 0;
    bool     path_active     = false;
    int64_t  override_last_us = 0;   /* timestamp of last valid LP override */
    control_frame_t last_override = {0};
#define OVERRIDE_TIMEOUT_US 300000LL /* revert to PP if no override for 300 ms */

    for (;;) {
        int64_t now_us = esp_timer_get_time();
        float dt_s = (float)(now_us - prev_us) * 1e-6f;
        if (dt_s < 0.005f) dt_s = 0.005f;
        if (dt_s > 0.200f) dt_s = 0.200f;
        prev_us = now_us;

        /* ── 1. Accept streaming chunk from ESP32-S3 ────────────────────── */
        path_chunk_t chunk;
        if (uart_bridge_recv_path_chunk(&chunk)) {

            /* First chunk of a new plan: capture SE(2) transform so that all
             * subsequent chunks of this plan are expressed in Wemos local frame.
             * The transform aligns wp[0] (S3's estimate of robot position) with
             * the current Wemos odometry pose. */
            if (chunk.start_index == 0 && chunk.path_id != s_tf_path_id) {
                odom_pose_t op;
                task_odometry_copy_pose(&op);
                s_tf_wx      = op.x * 1000.0f;
                s_tf_wy      = op.y * 1000.0f;
                s_tf_wth     = op.theta;
                s_tf_base_x  = chunk.wp[0].x;
                s_tf_base_y  = chunk.wp[0].y;
                s_tf_base_th = chunk.wp[0].theta;
                float dth    = wrap_rad(s_tf_wth - s_tf_base_th);
                s_tf_c       = cosf(dth);
                s_tf_sv      = sinf(dth);
                s_tf_dth     = dth;
                s_tf_path_id = chunk.path_id;
                path_active  = true;
                ESP_LOGI(TAG, "new path id=%u  local_start=(%.0f, %.0f)",
                         (unsigned)chunk.path_id,
                         (double)s_tf_wx, (double)s_tf_wy);
            }

            /* Apply stored transform and append to PP ring. */
            if (chunk.path_id == s_tf_path_id) {
                apply_transform_to_chunk(&chunk);
                if (!pp_append_chunk(&pp, &chunk)) {
                    /* Out-of-order chunk — tell ESP32-S3 what index we need. */
                    uart_bridge_send_chunk_nack(chunk.path_id,
                                                pp_get_expected_start_idx(&pp));
                    ESP_LOGW(TAG, "NACK path=%u expected=%u got=%u",
                             (unsigned)chunk.path_id,
                             (unsigned)pp_get_expected_start_idx(&pp),
                             (unsigned)chunk.start_index);
                }
            } else {
                /* chunk.path_id unknown (transform not yet computed because
                 * start_index != 0 arrived first) — NACK to force resend from 0. */
                uart_bridge_send_chunk_nack(chunk.path_id, 0u);
            }
        }

        /* ── 2. Current fused pose (metres → mm) ───────────────────────── */
        odom_pose_t op;
        task_odometry_copy_pose(&op);
        pose_t pose = {
            .x     = op.x * 1000.0f,
            .y     = op.y * 1000.0f,
            .theta = op.theta,
        };

        /* Shift reference forward to the front axle (260 mm ahead). */
        pose_t front_pose = {
            .x     = pose.x + cosf(pose.theta) * 260.0f,
            .y     = pose.y + sinf(pose.theta) * 260.0f,
            .theta = pose.theta,
        };

        /* ── 3 & 4. Override check, then PP command ──────────────────────── *
         * IMPORTANT: pp_compute_command() must NOT be called during an       *
         * override.  That function advances pursuit_idx (and frees ring      *
         * slots) based on the robot's current position.  While the Wemos is  *
         * executing a reactive/escape manoeuvre the robot is off-path, so    *
         * pursuit_idx would skip forward to a later segment.  When the       *
         * override expires PP would then resume at the wrong waypoint,        *
         * silently skipping the section of the A* path the car never drove.  */

        float applied_steer_deg = 90.0f;

        control_frame_t lp_override;
        bool have_override = uart_bridge_recv_control_override(&lp_override);
        if (have_override) {
            last_override    = lp_override;
            override_last_us = now_us;
        }

        bool override_active = have_override ||
                               (now_us - override_last_us < OVERRIDE_TIMEOUT_US);

        if (override_active) {
            lp_override = last_override;
            /* Apply local-planner command.
             * t_speed == 0 → full stop (LP_MODE_STOPPED / footprint occupied).
             * |heading_err| > 90° means the planner wants to reverse (ESCAPE). */
            if (lp_override.t_speed <= 0.0f) {
                motor_set(0.0f);
                servo_set_deg(90.0f);
                task_odometry_set_steering_rad(0.0f);
            } else {
                /* Convert S3 world-frame heading to Wemos local frame using the
                 * stored SE(2) angular offset (captured at last path receipt).
                 * Without this, the π/2 initial heading difference between frames
                 * makes forward reactive/escape commands trigger reverse. */
                float t_hdg = (s_tf_path_id != 0xFFFFu)
                              ? wrap_rad(lp_override.t_heading + s_tf_dth)
                              : lp_override.t_heading;
                float heading_err = wrap_rad(t_hdg - pose.theta);
                bool  is_reverse  = (heading_err >  (float)(M_PI / 2.0) ||
                                     heading_err < -(float)(M_PI / 2.0));
                float steer_rad;
                if (is_reverse) {
                    steer_rad = wrap_rad(heading_err - (float)M_PI);
                    if (steer_rad >  SERVO_MAX_STEER_RAD) steer_rad =  SERVO_MAX_STEER_RAD;
                    if (steer_rad < -SERVO_MAX_STEER_RAD) steer_rad = -SERVO_MAX_STEER_RAD;
                    ESP_LOGI(TAG, "REVERSE  t_hdg=%.0f° pose.th=%.0f° err=%.0f° spd=%.0f override_age=%lld us",
                             (double)(t_hdg * 180.0f / (float)M_PI),
                             (double)(pose.theta * 180.0f / (float)M_PI),
                             (double)(heading_err * 180.0f / (float)M_PI),
                             (double)lp_override.t_speed,
                             (long long)(now_us - override_last_us));
                    motor_set(-lp_override.t_speed);
                } else {
                    steer_rad = heading_err;
                    if (steer_rad >  SERVO_MAX_STEER_RAD) steer_rad =  SERVO_MAX_STEER_RAD;
                    if (steer_rad < -SERVO_MAX_STEER_RAD) steer_rad = -SERVO_MAX_STEER_RAD;
                    motor_set(lp_override.t_speed);
                }
                float steer_deg = 90.0f + steer_rad * (180.0f / (float)M_PI);
                applied_steer_deg = steer_deg;
                servo_set_deg(steer_deg);
                task_odometry_set_steering_rad(steer_rad);
            }
        } else if (path_active) {
            /* Only advance pursuit_idx when PP is actually in control */
            pp_motion_command_t cmd = pp_compute_command(&pp, &front_pose);
            if (cmd.stop) {
                motor_set(0.0f);
                servo_set_deg(90.0f);
                task_odometry_set_steering_rad(0.0f);
                uart_bridge_send_path_done();
                path_active = false;
                ESP_LOGI(TAG, "path complete  pose=(%.0f mm, %.0f mm, %.1f°)",
                         (double)pose.x, (double)pose.y,
                         (double)(pose.theta * 180.0f / (float)M_PI));
            } else {
                float steer_rad = (cmd.steering_deg - 90.0f) * ((float)M_PI / 180.0f);
                applied_steer_deg = cmd.steering_deg;
                servo_set_deg(cmd.steering_deg);
                motor_set(cmd.speed_mm_s);
                task_odometry_set_steering_rad(steer_rad);
            }
        } else {
            motor_set(0.0f);
            servo_set_deg(90.0f);
            task_odometry_set_steering_rad(0.0f);
        }

        /* ── 5. Send odom_t to ESP32-S3 ────────────────────────────────── */
        float cur_dist    = imu_encoder_driver_get_distance_m();
        float cur_heading = imu_encoder_driver_get_yaw_rad();

        float disp_mm  = (cur_dist - prev_dist_m) * 1000.0f;
        float dheading = wrap_rad(cur_heading - prev_heading);

        prev_dist_m  = cur_dist;
        prev_heading = cur_heading;

        odom_t pkt = {
            .linear_disp_mm   = disp_mm,
            .yaw_rate_imu     = dheading / dt_s,
            .dt_ms            = dt_s * 1000.0f,
            .seq              = odom_seq++,
            .consumed_wp_idx  = pp_get_consumed_idx(&pp),
            .consumed_path_id = pp_get_path_id(&pp),
        };
        uart_bridge_send_odom(&pkt);

        ESP_LOGD(TAG,
                 "odom: disp=%.2f mm  rate=%.3f r/s  steer=%.1f°  ring=%u  active=%d",
                 (double)pkt.linear_disp_mm, (double)pkt.yaw_rate_imu,
                 (double)applied_steer_deg,
                 (unsigned)pp_get_expected_start_idx(&pp), (int)path_active);

        vTaskDelay(pdMS_TO_TICKS(PP_PERIOD_MS));
    }
}

/* ════════════════════════════════════════════════════════════════════════════
 * Hardware init
 * ════════════════════════════════════════════════════════════════════════════ */

static void motor_ledc_init(void)
{
    ledc_timer_config_t tmr = {
        .speed_mode      = LEDC_LOW_SPEED_MODE,
        .duty_resolution = MOTOR_PWM_RES,
        .timer_num       = LEDC_TIMER_1,
        .freq_hz         = MOTOR_PWM_FREQ_HZ,
        .clk_cfg         = LEDC_AUTO_CLK,
    };
    ledc_timer_config(&tmr);

    ledc_channel_config_t fwd = {
        .gpio_num = MOTOR_F_PIN, .speed_mode = LEDC_LOW_SPEED_MODE,
        .channel  = CH_FWD,      .timer_sel  = LEDC_TIMER_1,
        .duty = 0, .hpoint = 0,
    };
    ledc_channel_config(&fwd);

    ledc_channel_config_t bwd = {
        .gpio_num = MOTOR_B_PIN, .speed_mode = LEDC_LOW_SPEED_MODE,
        .channel  = CH_BWD,      .timer_sel  = LEDC_TIMER_1,
        .duty = 0, .hpoint = 0,
    };
    ledc_channel_config(&bwd);
}

static void servo_ledc_init(void)
{
    ledc_timer_config_t tmr = {
        .speed_mode      = LEDC_LOW_SPEED_MODE,
        .duty_resolution = SERVO_PWM_RES,
        .timer_num       = LEDC_TIMER_0,
        .freq_hz         = SERVO_PWM_FREQ_HZ,
        .clk_cfg         = LEDC_AUTO_CLK,
    };
    ledc_timer_config(&tmr);

    ledc_channel_config_t ch = {
        .gpio_num = SERVO_PIN,  .speed_mode = LEDC_LOW_SPEED_MODE,
        .channel  = SERVO_CH,   .timer_sel  = LEDC_TIMER_0,
        .duty = SERVO_DUTY_CENTER, .hpoint = 0,
    };
    ledc_channel_config(&ch);
}

/* ════════════════════════════════════════════════════════════════════════════
 * app_main
 * ════════════════════════════════════════════════════════════════════════════ */
void app_main(void)
{
    uart_bridge_init();

    if (!imu_gyro_init()) {
        ESP_LOGE(TAG, "IMU init failed — check I2C SDA=%d SCL=%d",
                 WEMOS_I2C_SDA, WEMOS_I2C_SCL);
        for (;;) vTaskDelay(pdMS_TO_TICKS(1000));
    }

    float bias = imu_gyro_calibrate_bias(300);
    ESP_LOGI(TAG, "gyro bias = %.5f rad/s", (double)bias);

    motor_ledc_init();
    servo_ledc_init();
    servo_set_deg(90.0f);

    xTaskCreate(task_odometry,     "odom", 4096, NULL, 5, NULL);
    xTaskCreate(task_pure_pursuit, "pp",   4096, NULL, 4, NULL);
}

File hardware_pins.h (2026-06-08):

/**
 * hardware_pins.h
 * Central pin assignments for the SLAMborghini two-board hardware.
 *
 * Two-board architecture:
 *   ESP32-S3  (SLAM brain)       — LiDAR + IMU + SLAM + Wi-Fi dashboard
 *   Wemos D1 R32 (ESP32)         — motors + servo + AS5600 encoder + HC-SR04
 *
 * UART cross-connections:
 *   ESP32-S3 GPIO17 (BRIDGE_TX_PIN)  → Wemos GPIO16  (WEMOS_BRIDGE_RX_PIN)
 *   Wemos    GPIO17 (WEMOS_BRIDGE_TX_PIN) → ESP32-S3 GPIO16 (BRIDGE_RX_PIN)
 *
 * Edit only this file when rewiring.
 */

#ifndef HARDWARE_PINS_H
#define HARDWARE_PINS_H

#include "driver/uart.h"
#include "driver/gpio.h"

/* ══════════════════════════════════════════════════════════════════════════
 * ESP32-S3 — RPLiDAR C1 UART  (UART_NUM_1)
 * ══════════════════════════════════════════════════════════════════════════ */
#define LIDAR_UART_PORT   UART_NUM_1
#define LIDAR_UART_RX     14     /* LiDAR TX (yellow) → ESP32-S3 GPIO14    */
#define LIDAR_UART_TX     13     /* ESP32-S3 GPIO13 → LiDAR RX (green)     */
#define LIDAR_BAUD        460800


/* ══════════════════════════════════════════════════════════════════════════
 * ESP32-S3 → Wemos UART bridge  (UART_NUM_2)
 * ══════════════════════════════════════════════════════════════════════════ */
#define BRIDGE_UART_PORT  UART_NUM_2
#define BRIDGE_TX_PIN     GPIO_NUM_17  /* ESP32-S3 GPIO17 → Wemos GPIO16   */
#define BRIDGE_RX_PIN     GPIO_NUM_16  /* Wemos GPIO17    → ESP32-S3 GPIO16 */
#define BRIDGE_BAUD       921600

/* ══════════════════════════════════════════════════════════════════════════
 * Wemos D1 R32 — IBT-4 motor driver
 * ══════════════════════════════════════════════════════════════════════════ */
#define MOTOR_F_PIN       19     /* IO19 → IBT-4 IN1 (forward)             */
#define MOTOR_B_PIN       13     /* IO13 → IBT-4 IN2 (backward)            */

/* ══════════════════════════════════════════════════════════════════════════
 * Wemos D1 R32 — steering servo (PWM)
 * IO2 on the analog header of the Wemos D1 R32 = GPIO2.
 * ══════════════════════════════════════════════════════════════════════════ */
#define SERVO_PIN         2

/* ══════════════════════════════════════════════════════════════════════════
 * Wemos D1 R32 — shared I2C bus  (I2C_NUM_0)
 * Both the ICM-20948 IMU (addr 0x68) and the AS5600 encoder (addr 0x36)
 * share this bus.  Initialise I2C once; then address each device separately.
 * ══════════════════════════════════════════════════════════════════════════ */
#define WEMOS_I2C_SDA     21     /* shared SDA for IMU + encoder            */
#define WEMOS_I2C_SCL     22     /* shared SCL for IMU + encoder            */

/* Aliases used by imu_gyro.c */
#define IMU_I2C_PORT      I2C_NUM_0
#define IMU_SDA_PIN       WEMOS_I2C_SDA
#define IMU_SCL_PIN       WEMOS_I2C_SCL

/* Aliases used by AS5600 test / future encoder driver */
#define ENCODER_SDA_PIN   WEMOS_I2C_SDA
#define ENCODER_SCL_PIN   WEMOS_I2C_SCL

/* ══════════════════════════════════════════════════════════════════════════
 * Wemos D1 R32 — HC-SR04 ultrasonic sensors
 * Two sensors wired on four GPIOs.
 * TODO: verify which of each pair is TRIG vs ECHO.
 * ══════════════════════════════════════════════════════════════════════════ */
#define SONAR_A_TRIG_PIN  14
#define SONAR_A_ECHO_PIN  27
#define SONAR_B_TRIG_PIN  25
#define SONAR_B_ECHO_PIN  26

/* ══════════════════════════════════════════════════════════════════════════
 * Wemos D1 R32 — UART from ESP32-S3  (UART_NUM_2)
 * GPIO16/17 freed when LiDAR moved to the ESP32-S3.
 * ══════════════════════════════════════════════════════════════════════════ */
#define WEMOS_BRIDGE_UART_PORT  UART_NUM_2
#define WEMOS_BRIDGE_RX_PIN     16   /* from ESP32-S3 GPIO17                */
#define WEMOS_BRIDGE_TX_PIN     17   /* to   ESP32-S3 GPIO16                */
#define WEMOS_BRIDGE_BAUD       921600

#endif /* HARDWARE_PINS_H */

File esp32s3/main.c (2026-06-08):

/**
 * esp32s3/main.c  —  Phase 2: LiDAR + Odometry → Quadtree → Dashboard
 *
 * ════════════════════════════════════════════════════════════════════════════
 * WHAT THIS DOES
 * ════════════════════════════════════════════════════════════════════════════
 * Two tasks on Core 0 run the sensing + localisation pipeline:
 *
 *   task_lidar_slam  (prio 7)
 *     1. Read one 360° LiDAR scan  (~100 ms)
 *     2. Snapshot the current pose AFTER the scan (most current estimate)
 *     3. Ray-march the scan into the quadtree occupancy map  (~15 ms)
 *     4. Push updated map + scan overlay to the browser dashboard
 *     5. Sleep 20 ms to yield CPU to httpd / _dash_task
 *     Repeat.
 *
 *   task_odom  (prio 6)
 *     Drains odom_t packets from the Wemos over UART bridge at 100 Hz.
 *     Each packet carries linear displacement (mm) and IMU yaw rate (rad/s).
 *     Integrates them into s_pose using midpoint Runge-Kutta under mutex.
 *
 * Result on the dashboard:
 *   - Move the car forward → car marker moves across the fixed map
 *   - Turn the car in place → car marker rotates; the MAP stays fixed
 *   The map is always in a fixed world frame. Only the car pose changes.
 *
 * ════════════════════════════════════════════════════════════════════════════
 * TASKS
 * ════════════════════════════════════════════════════════════════════════════
 *   task_lidar_slam   Core 0  prio 7   stack 6 KB
 *   task_odom         Core 0  prio 6   stack 3 KB
 *   task_perf_mon     Core 0  prio 1   stack 3 KB
 *   _dash_task        Core 0  prio 1   stack 4 KB   (inside wifi_dashboard.c)
 *
 * ════════════════════════════════════════════════════════════════════════════
 * MEMORY LAYOUT
 * ════════════════════════════════════════════════════════════════════════════
 *
 *   WHERE    WHAT                           SIZE        HOW ALLOCATED
 *   ───────  ─────────────────────────────  ──────────  ──────────────────────
 *   BSS      s_map  (header + node pool)    48 KB       global static
 *            4000 nodes × 12 B/node â no heap allocation
 *
 *   BSS      s_scan  (lidar_scan_t)         5.4 KB      static local in task
 *            460 points × 12 B/point + 12 B header
 *            *** declared `static` inside task_lidar_slam so it goes to BSS,
 *                NOT onto the 6 KB task stack.  Without static it would
 *                immediately overflow the stack. ***
 *
 *   HEAP     task stacks
 *            task_lidar_slam                6 KB        xTaskCreatePinnedToCore
 *            task_odom                      3 KB        xTaskCreate
 *            task_perf_mon                  3 KB        xTaskCreate
 *            _dash_task  (wifi_dash)        4 KB        xTaskCreate (inside init)
 *
 *   BSS      wifi_dashboard.c internal      ~12 KB      global statics in that TU
 *
 *   TOTAL HEAP:  ~14 KB pool + ~16 KB task stacks  ≈ 30 KB
 *   TOTAL BSS:   ~17 KB
 *   ESP32-S3 has ~320 KB free DRAM after IDF + WiFi → comfortable margin.
 *
 * ════════════════════════════════════════════════════════════════════════════
 * CPU PRIORITY NOTE
 * ════════════════════════════════════════════════════════════════════════════
 *   IDF WiFi driver tasks run at priority 23 — always preempt our tasks.
 *   IDF LwIP/TCP stack runs at priority 18 — also above us.
 *   httpd server runs at priority 5 — below our tasks.
 *   → 20 ms vTaskDelay after each scan gives httpd (prio 5) CPU to flush
 *     TCP ACKs. The scan UART-read already yields ~100 ms when no buffered
 *     scan is ready; the explicit delay matters only when scans are pre-buffered.
 *
 *   User task priority layout (Core → Pri):
 *     task_lidar_slam  Core 0  prio 7  — scan-match + map write + LOCAL PLANNER
 *     task_odom        Core 0  prio 6  — wheel/IMU odometry + path streamer tick
 *     task_path_exec   Core 1  prio 4  — must preempt task_planner immediately
 *                                        when a new path is published, especially
 *                                        after an LP-triggered replan
 *     task_planner     Core 1  prio 3  — A* + frontier selection (holds map mutex)
 *     task_perf_mon    Core 1  prio 1  — stats only
 *
 *   The local planner runs INSIDE task_lidar_slam (prio 7) immediately after
 *   the map write.  It reads the map without s_map_mutex — safe because it is
 *   in the same task that just finished writing, and qt_query_const never writes.
 */

/* ── Wi-Fi credentials — fill in before flashing ───────────────────────── */
#define WIFI_SSID      "SPOT-iot"
#define WIFI_PASSWORD  "RacailleSalutaireMigration8052"

#include "../hardware_pins.h"
#include "src/lidar_driver.h"
#include "src/lidar_to_map.h"
#include "src/quadtree_map.h"
#include "src/scan_matcher.h"
#include "src/wifi_dashboard.h"
#include "src/uart_bridge.h"
#include "src/path_streamer.h"
#include "src/frontier_detector.h"
#include "src/hybrid_astar.h"
#include "src/local_planner.h"
#include "src/obstacle_classifier.h"

#include "freertos/FreeRTOS.h"
#include "freertos/task.h"
#include "freertos/semphr.h"
#include "esp_timer.h"
#include "esp_heap_caps.h"
#include "esp_system.h"
#include <math.h>
#include <stdbool.h>
#include <stdio.h>


/* ════════════════════════════════════════════════════════════════════════════
 * Shared state
 * ════════════════════════════════════════════════════════════════════════════ */

/* Map header and node pool both in static BSS (see qt_init); no heap allocation. */
static quadtree_map_t s_map;

/* Robot pose in the fixed world frame (mm, rad).
 * Written by task_odom, read by task_lidar_slam — always under s_pose_mutex. */
static pose_t s_pose;

/* Task handles — used by task_perf_mon to read stack watermarks. */
static TaskHandle_t s_h_lidar = NULL;
static TaskHandle_t s_h_odom  = NULL;
static TaskHandle_t s_h_perf  = NULL;

/* Protects s_pose between task_odom (writer) and task_lidar_slam (reader). */
static SemaphoreHandle_t s_pose_mutex = NULL;

/* ── Diagnostic counters ─────────────────────────────────────────────────── *
 * Written by task_lidar_slam, read by task_perf_mon.  No mutex needed —     *
 * perf_mon is allowed to read a value that is one update behind.            */
static volatile uint32_t s_scans_ok   = 0;
static volatile uint32_t s_scans_bad  = 0;

static volatile uint32_t s_read_us_tot = 0;
static volatile uint32_t s_read_us_max = 0;

static volatile uint32_t s_l2m_calls  = 0;
static volatile uint32_t s_l2m_us_tot = 0;
static volatile uint32_t s_l2m_us_max = 0;

/* Scan-matcher diagnostics */
static volatile uint32_t s_sm_calls   = 0;   /* total scan_match() invocations */
static volatile uint32_t s_sm_valid   = 0;   /* corrections accepted */
static volatile uint32_t s_sm_us_tot  = 0;   /* cumulative time in scan_match() */
static volatile uint32_t s_sm_us_max  = 0;   /* worst-case scan_match() time */

/* ── Planner / executor shared state ─────────────────────────────────────── */
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

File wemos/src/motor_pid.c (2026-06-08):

#include "motor_pid.h"
#include "imu_encoder_driver.h"

#include "freertos/FreeRTOS.h"
#include "freertos/task.h"
#include "driver/ledc.h"

/*
 * PID speed controller for the drive motor.
 *
 * The motor was previously driven at a fixed duty cycle (MOTOR_DUTY_FWD = 35),
 * which assumed the car always travels at exactly MOTOR_SPEED_MM_S = 346 mm/s.
 * In reality, speed varies with battery level, surface friction, and load.
 * This error propagates directly into dead_reckon_pose() — if the assumed speed
 * is wrong, the estimated position drifts from the real one every cycle.
 *
 * The PID closes the loop: it reads the actual speed from the AS5600 encoder
 * via imu_encoder_driver_get_speed_ms(), compares it to the target, and adjusts
 * the PWM duty cycle to keep the real speed close to the commanded value.
 */

static float s_integral  = 0.0f;
static float s_prev_err  = 0.0f;
static volatile float s_target_ms   = 0.0f;
static volatile bool  s_pid_running = false;

void motor_pid_reset(void)
{
    s_integral = 0.0f;
    s_prev_err = 0.0f;
}

/*
 * Anti-windup clamp on the integral term.
 *
 * Without this, if the motor is stalled or the encoder reads zero for several
 * cycles (e.g. at startup before the wheel starts moving), the integral
 * accumulates a very large value. When the motor finally spins up, the PID
 * output overshoots violently. Clamping to [-2, +2] bounds the worst-case
 * overshoot to a predictable range regardless of how long the motor was stalled.
 */
uint32_t motor_pid_update(float target_ms, float measured_ms, float dt_s)
{
    if (dt_s <= 0.0f) return MOTOR_DUTY_MIN;

    float err = target_ms - measured_ms;

    s_integral += err * dt_s;
    if (s_integral >  2.0f) s_integral =  2.0f;
    if (s_integral < -2.0f) s_integral = -2.0f;

    float deriv  = (err - s_prev_err) / dt_s;
    s_prev_err   = err;

    float output = 35.0f
                   + MOTOR_PID_KP * err
                   + MOTOR_PID_KI * s_integral
                   + MOTOR_PID_KD * deriv;

    if (output < (float)MOTOR_DUTY_MIN) output = (float)MOTOR_DUTY_MIN;
    if (output > (float)MOTOR_DUTY_MAX) output = (float)MOTOR_DUTY_MAX;

    return (uint32_t)output;
}

void motor_pid_set_target(float target_ms)
{
    s_target_ms   = target_ms;
    s_pid_running = (target_ms > 0.0f);
}

void motor_pid_stop(void)
{
    s_target_ms   = 0.0f;
    s_pid_running = false;
}

/*
 * Why a dedicated FreeRTOS task at 1 kHz instead of calling the PID inline?
 *
 * The original drive loop called imu_drive_and_track() which blocks for the
 * entire drive_ms duration — up to 1200 ms. Embedding the PID inside that
 * blocking call would tie it to the IMU polling interval (10 ms = 100 Hz),
 * which is too slow for stable speed regulation on a brushed DC motor.
 *
 * Running the PID as a pinned task on Core 1 at priority 24 gives it a
 * deterministic 1 ms period independent of what plan_task or scan_task are
 * doing on Core 0.
 */
void motor_pid_task(void *pvParameters)
{
    (void)pvParameters;
    motor_pid_reset();

    for (;;) {
        if (s_pid_running) {
            float measured = imu_encoder_driver_get_speed_ms();
            uint32_t duty  = motor_pid_update(s_target_ms, measured, 0.001f);

            ledc_set_duty(LEDC_LOW_SPEED_MODE, LEDC_CHANNEL_3, duty);
            ledc_update_duty(LEDC_LOW_SPEED_MODE, LEDC_CHANNEL_3);
        }
        vTaskDelay(pdMS_TO_TICKS(1));
    }
}
